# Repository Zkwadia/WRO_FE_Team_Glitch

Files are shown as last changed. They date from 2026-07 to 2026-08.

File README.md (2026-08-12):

# 🚗 WRO 2026 Future Engineers — Team Glitch

<div align="center">



</div>

---

## 🏆 WRO 2026 Future Engineers — India Nationals

Welcome to the GitHub repository of **Team Glitch**, competing in the **World Robot Olympiad™ (WRO®) Future Engineers 2026** category at the India National Finals. Our team is made up of students who designed, built, and programmed a fully autonomous self-driving vehicle to tackle the dynamic challenges of the WRO 2026 competition.

Our name, **Glitch**, reflects our engineering philosophy — finding the unexpected edge cases, the subtle bugs, and the tiny mis-alignments that make the difference between a run that scores and a run that doesn't. We don't just build a robot; we debug it relentlessly until every glitch is gone.

> *"Every test run is a debugging session. Every crash is data."*

**Current best times on the 3m × 3m field:**
- **Open Challenge**: ~50 seconds (full score)
- **Obstacle Challenge**: ~72 seconds (full score)
  
---

## 📚 Table of Contents

- [📂 Documentation Structure](#-documentation-structure)
- [👥 The Team](#-the-team)
- [🎯 Challenge Overview](#-challenge-overview)
- [🤖 Our Robot](#-our-robot)
- [🔧 Electronic Systems & Components](#-electronic-systems--components)
- [⚙️ Mechanical Systems](#️-mechanical-systems)
- [💻 Software Architecture](#-software-architecture)
- [🧭 Open Challenge — Strategy & Logic](#-open-challenge--strategy--logic)
- [🚧 Obstacle Challenge — Strategy & Logic](#-obstacle-challenge--strategy--logic)
- [🔄 Engineering Decisions & Iterations](#-engineering-decisions--iterations)
- [📹 Performance Videos](#-performance-videos)
- [🌐 GitHub Utilization](#-github-utilization)
- [📜 License](#-license)
- [🗓️ GitHub Commit Dates](#github-commit-dates)

---

## 📂 Documentation Structure

Each folder in this repository contains detailed technical content:

| Folder | Content | 
|---|---|
| `v-photos/` | Robot photos — 6 angles + labelled component view |
| `t-photos/` | Team photos — official and fun |
| `schemes/` | Wiring diagram, power architecture |
| `models/` | 3D print STL files, STEP CAD files for polycarbonate cuts |
| `src/` | Main Python scripts — obstacle and open challenge |
| `versionTest/` | Test Python scripts — All modules testing|
| `other/` | Component images used in this README |

---

## 👥 The Team

**Official Team Photo**

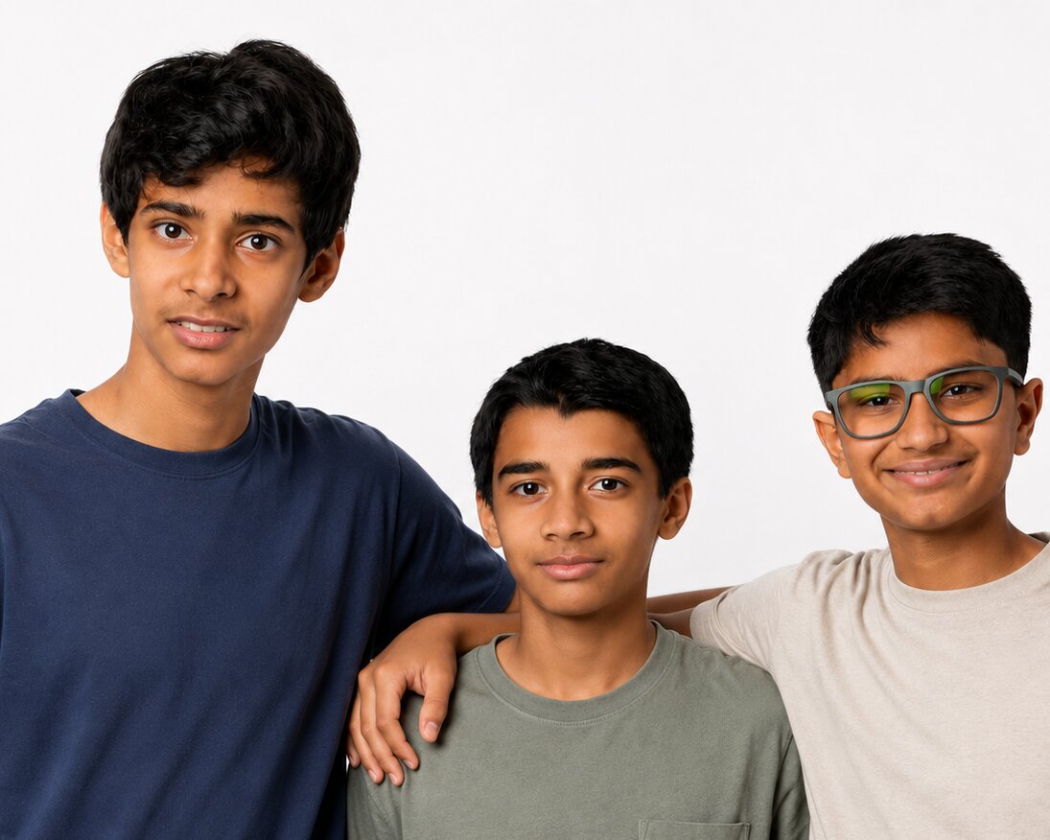
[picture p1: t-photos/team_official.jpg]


---

| Member | Role | Background | About |
|---|---|---|---|
| **Shaurya Sule** | Documentation, Electronics, Strategy | 9th Grade | Shaurya is a Grade 9 student at Dhirubhai Ambani International School with a strong interest in robotics and debate. He has participated in WRO multiple times, including competing at the World Championships and achieving 3rd place. He is also the captain of his FTC team, where he develops leadership, engineering, and problem solving skills. Alongside robotics, he is an accomplished debater and has won multiple debate championships across India.|
| **Rehaan Dhandhia** | Software, Vision & Sensor Integration | 9th Grade | Rehaan is a Grade 9 student at Dhirubhai Ambani International School. He has participated in WRO for four years and achieved 3rd place at the WRO World Finals in 2023. He has also been involved in FIRST Tech Challenge (FTC) for the past two years. Through robotics, he has developed skills in programming, electronics, and problem solving. Outside robotics, he enjoys mathematics and physics, has played the piano for eight years, and has competed in state level badminton tournaments.|
| **Zeus Wadia** | Electronics, Testing, Mechanical Design | 9th Grade | Zeus is a Grade 9 student at Nita Mukesh Ambani Junior School, Mumbai, with a strong interest in robotics and engineering. He has competed in WRO and FTC, gaining experience in robot design, electronics, programming, and autonomous systems. In 2025, he placed 12th at the WRO Future Innovators Junior National Finals and has participated in FTC for the past two years.|

**Coach:** **Ajinkya Giri** — Robotics Engineer and Mentor

**Fun Team Photo:**
This photo is from the 2025 WRO India nationals, where the 3 of us competed as a team in the Future Innovators category and eventually placed 12th.
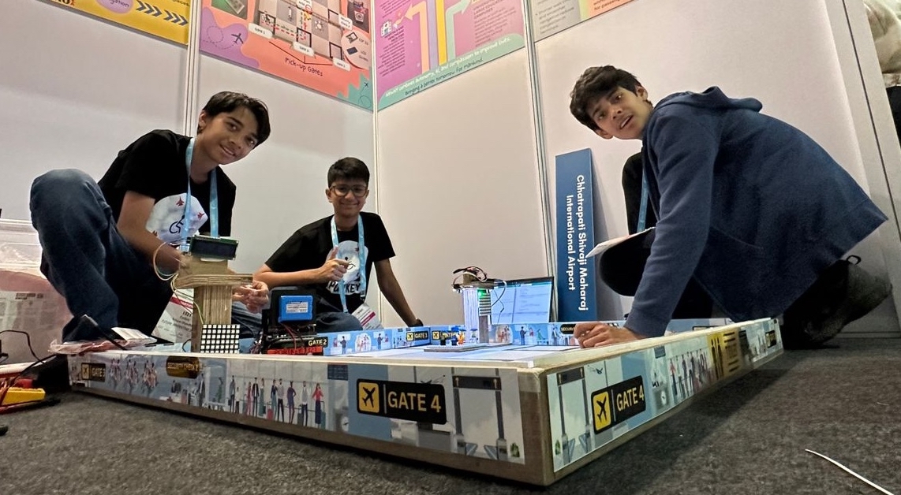
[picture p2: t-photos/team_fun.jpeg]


### Team Journey

Throughout development — from first chassis cut to nationals — we logged every run, debugged every crash, and iterated on every subsystem. The photos below capture key moments from that process.

**Testing session photo:** Tuning robot parking (setting up obstacle challenge).

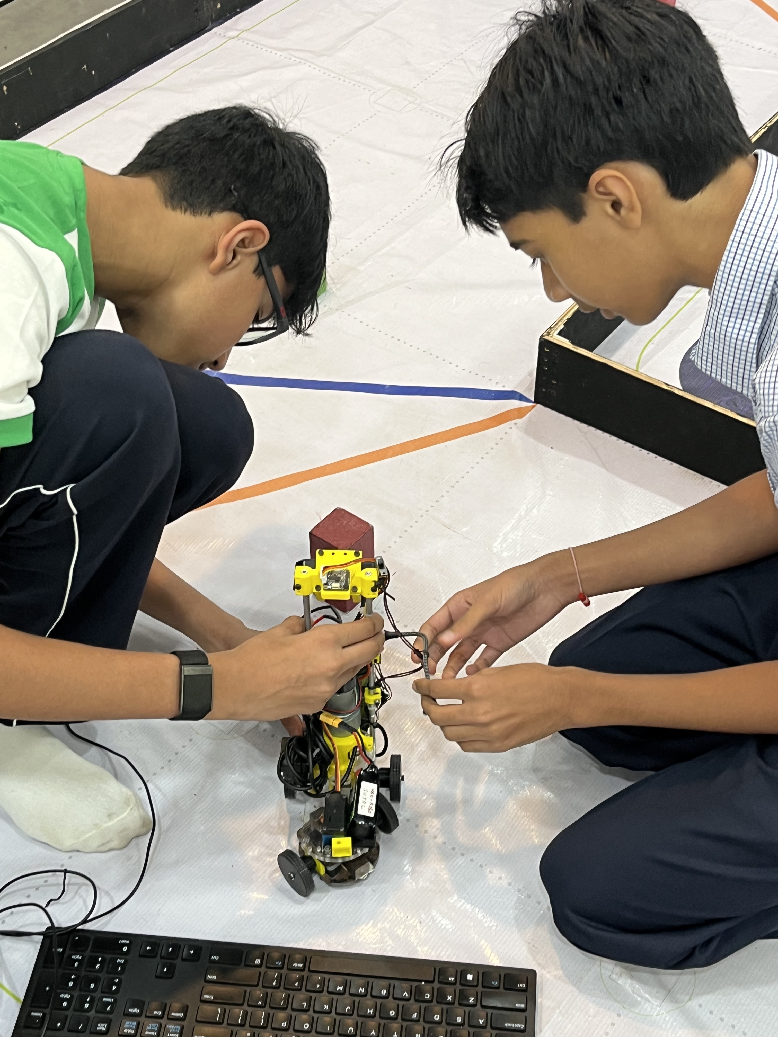
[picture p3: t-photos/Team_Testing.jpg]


---

## 🎯 Challenge Overview

WRO 2026 Future Engineers is a self-driving car challenge on a 3m × 3m racetrack that changes configuration every round.

### Open Challenge

| Aspect | Requirement | Our Approach |
|---|---|---|
| **Track Variability** | Random internal wall placements | Outer wall centroid PD — adapts to any corridor width |
| **Navigation** | Unknown layout each round | Camera wall detection + IMU heading hold |
| **Lap Count** | 3 laps, stop at start | Counter + `last_wall` camera zone + IMU heading snap |
| **Speed** | Sub-60s target | 85% PWM, smoothed ramp, no speed PID needed |

### Obstacle Challenge

| Aspect | Requirement | Our Approach |
|---|---|---|
| **Traffic Signs** | Red → right, Green → left | OpenCV HSV centroid PD, 2-state avoidance |
| **Lap Count** | 3 laps | Floor line colour trigger, encoder odometry |
| **Parking** | Fully inside lot, parallel to wall | 4-state parking state machine + TFmini Plus proximity |
| **Direction** | Detected at start | Side wall distance + outer wall camera zone |

### WRO 2026 Documentation Scoring (30 Points)

| Area | Max Points | Our Coverage |
|---|---:|---|
| **1. Mobility & Mechanical Design** | 6 | Motor selection, Parallel steering system, custom polycarbonate chassis, drive system, encoder integration |
| **2. Power & Sensor Architecture** | 6 | Dual rail power system, TFmini Plus LiDAR, BNO085 IMU, sensor placement, wiring diagrams |
| **3. Software Architecture & Obstacle Strategy** | 6 | State machines, HSV vision pipeline, centroid based PD control, obstacle avoidance logic, parking sequence, source code |
| **4. Systems Thinking & Engineering Decisions** | 6 | Design iterations, subsystem integration, engineering tradeoffs, decision rationale, risk mitigation |
| **5. Reproducibility & GitHub Quality** | 6 | Structured repository, commit history, README, CAD files, wiring diagrams, full documentation, replication guide |
| **Total** | **30** | |

### Educational Objectives

- **Computer Vision**: Real-world HSV colour segmentation, zone-based detection, LAB colour space
- **Control Systems**: PID steering, closed-loop speed control, positional vs. incremental PID
- **Embedded Systems**: Multiprocessing on Linux, UART communication, I2C sensor management
- **Systems Engineering**: Process isolation, shared memory, fault recovery
- **Engineering Documentation**: Decision rationale, iteration history, replication guides

---

## 🤖 Our Robot

<div align="center">

<table>
  <tr>
    <td align="center"><b>Front View</b></td>
    <td align="center"><b>Rear View</b></td>
  </tr>
  <tr>
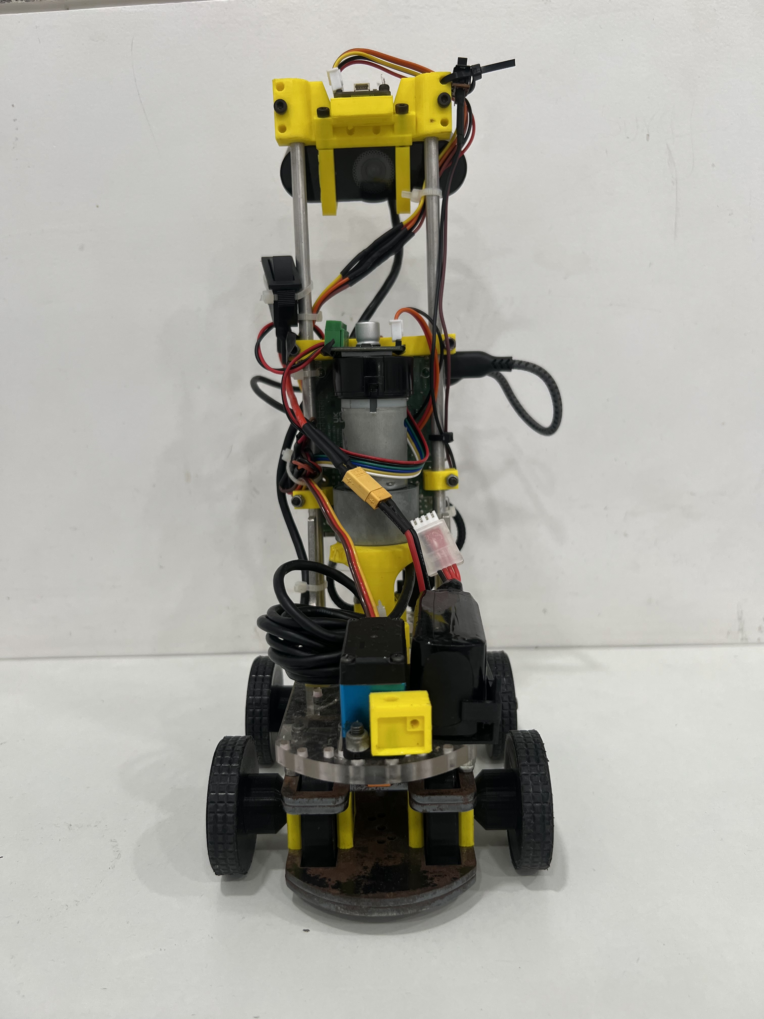
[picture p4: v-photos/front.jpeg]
    <td></td>
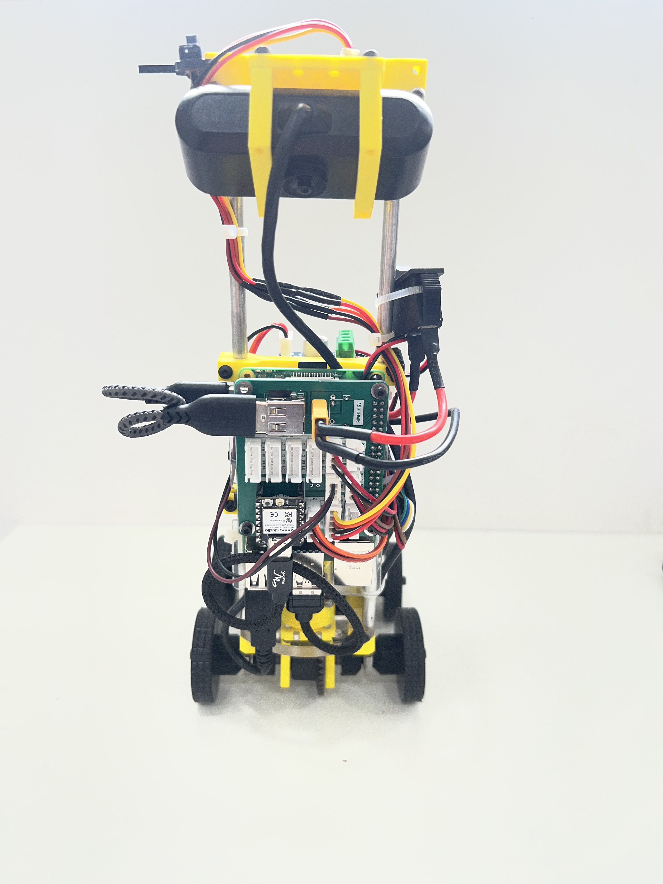
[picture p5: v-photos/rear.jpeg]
    <td></td>
  </tr>
  <tr>
    <td align="center"><b>Left Side</b></td>
    <td align="center"><b>Right Side</b></td>
  </tr>
  <tr>
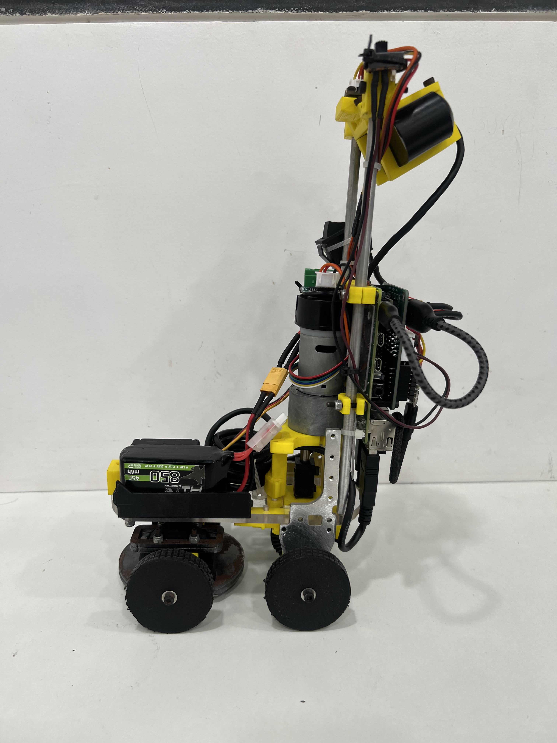
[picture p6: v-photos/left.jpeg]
    <td></td>
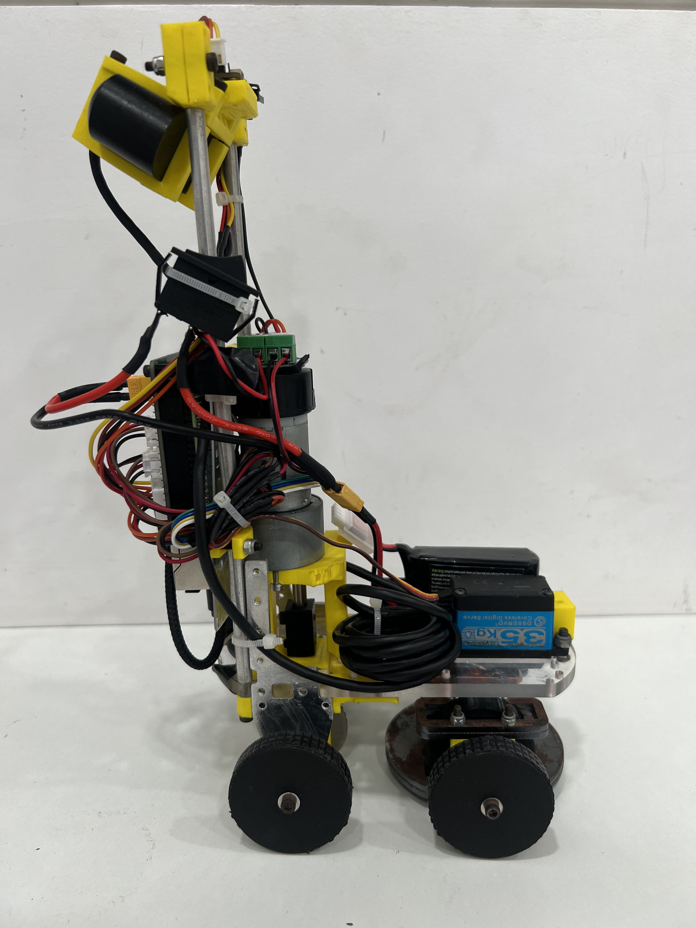
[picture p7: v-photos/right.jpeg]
    <td></td>
  </tr>
  <tr>
    <td align="center"><b>Top View</b></td>
    <td align="center"><b>Bottom View</b></td>
  </tr>
  <tr>
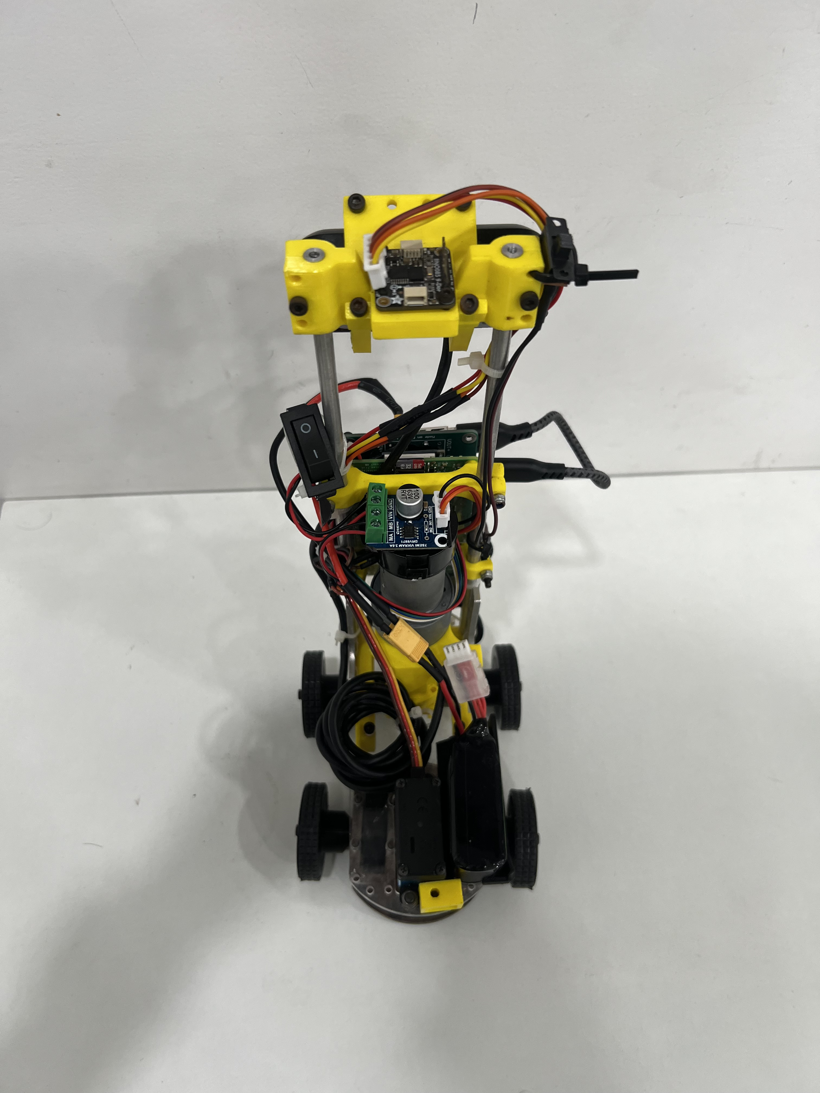
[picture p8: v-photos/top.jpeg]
    <td></td>
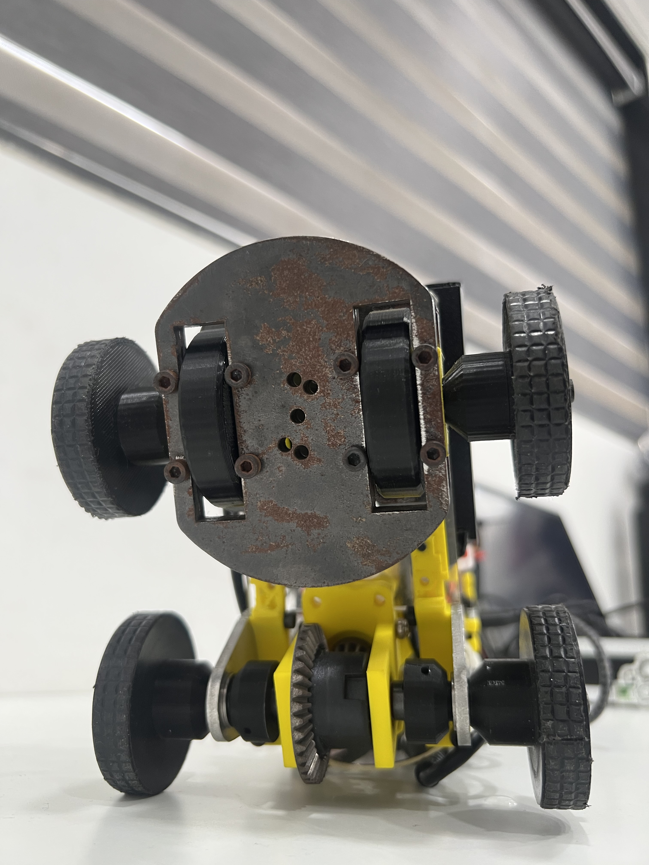
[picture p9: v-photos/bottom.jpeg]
    <td></td>
  </tr>
  <tr>
    <td colspan="2" align="center"><b>Labelled Component View</b></td>
  </tr>
  <tr>
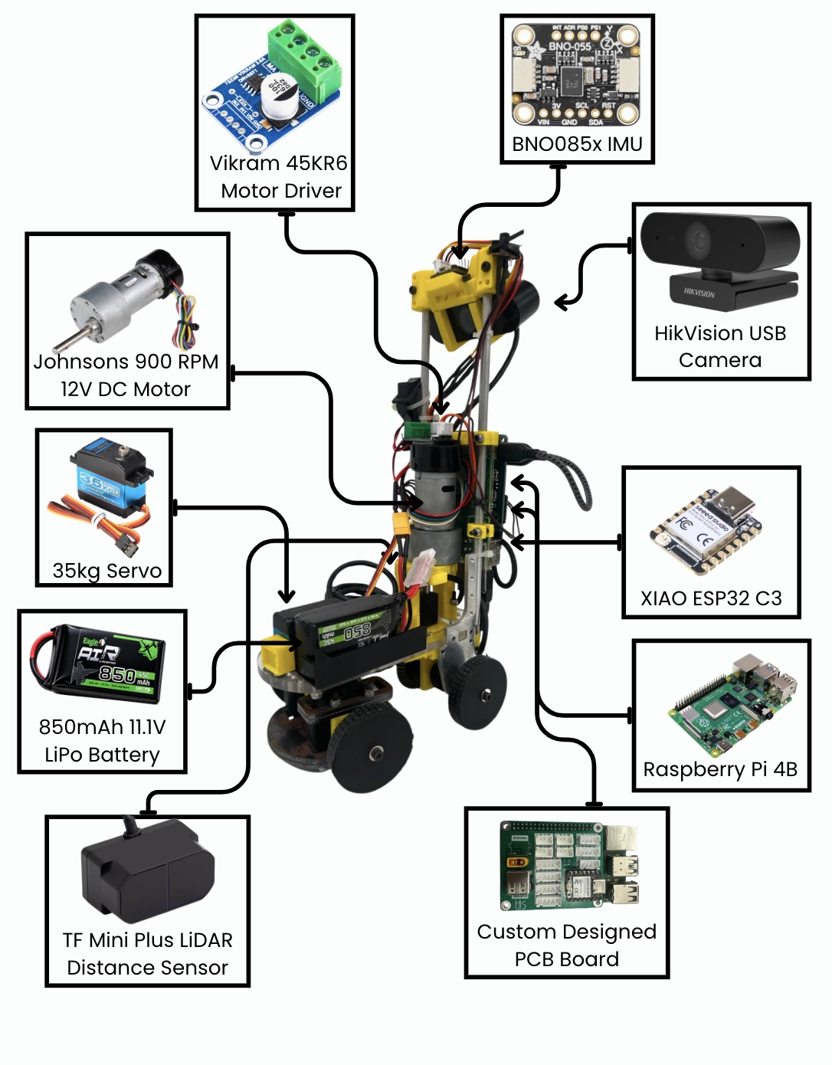
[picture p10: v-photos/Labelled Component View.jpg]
    <td colspan="2" align="center"></td>
  </tr>
</table>

</div>

### Key Specifications

| Parameter | Value |
|---|---|
| **Dimensions** | [190] × [120] × [300] mm |
| **Weight** | ~[1.310] kg |
| **Drive Type** | Rear-wheel drive, 12V DC geared motor + external quadrature encoder |
| **Steering** | Servo-actuated parallel steering system |
| **Primary Brain** | Raspberry Pi 4 Model B (4 GB) |
| **Co-processor** | Seeed XIAO ESP32-C3 (IMU + encoder over USB UART) |
| **Vision** | USB Camera + OpenCV HSV pipeline (no Edge TPU) |
| **Distance Sensor** | 1× TFmini Plus LiDAR (right side, UART, parking only) |
| **Heading** | Adafruit BNO085 9-DOF IMU (on XIAO, I2C) |
| **Max Speed** | ~90% PWM duty cycle |

### Performance Specifications

| Metric | Value |
|---|---|
| **Max theoretical speed** | ~[2] m/s (from 900RPM + wheel diameter) |
| **Operational speed** | ~[2.703] m/s (90% PWM, closed-loop) |
| **Battery capacity** | [850] mAh LiPo |
| **Camera FPS (live loop)** | ~25 FPS (with `cv2.imshow` disabled) |
| **IMU update rate** | 100Hz (BNO085 Euler output) |
| **UART baud rate** | 115200 (XIAO → Pi) |

---

## 🔧 Electronic Systems & Components

### Component List

| Component | Image | Specifications | Role | Source |
|---|---|---|---|---|
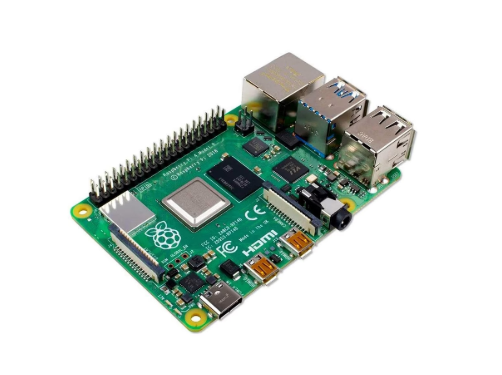
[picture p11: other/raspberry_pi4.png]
RPi4
| **Raspberry Pi 4 Model B (4GB)** |  | Quad-core Cortex-A72 @ 1.8GHz, 4 GB LPDDR4, USB 3.0, GPIO 40-pin | Main compute — vision, sensor fusion, PID control via pigpio | [robu.in](https://robu.in/product/raspberry-pi-4-model-b-with-4-gb-ram/) |
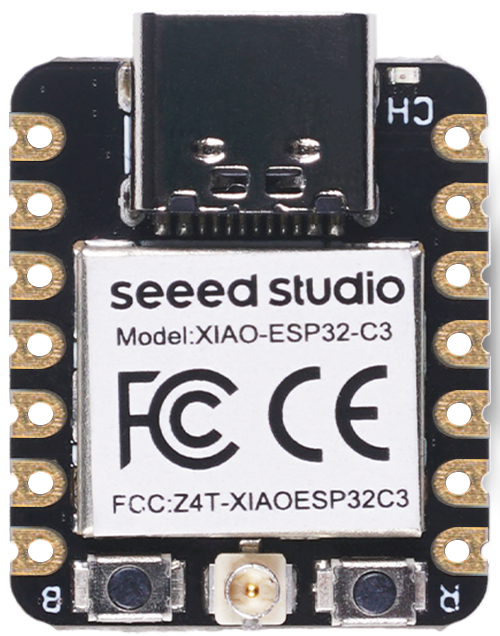
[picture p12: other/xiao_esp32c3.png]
XIAO
| **Seeed XIAO ESP32-C3** |  | ESP32-C3 RISC-V @160MHz, 400KB SRAM, USB-C, 3.3V logic, 21×17.5mm | Co-processor — BNO085 IMU + external encoder, streams to Pi at 115200 baud | [robu.in](https://robu.in/product/seeed-studio-xiao-esp32c3/) |
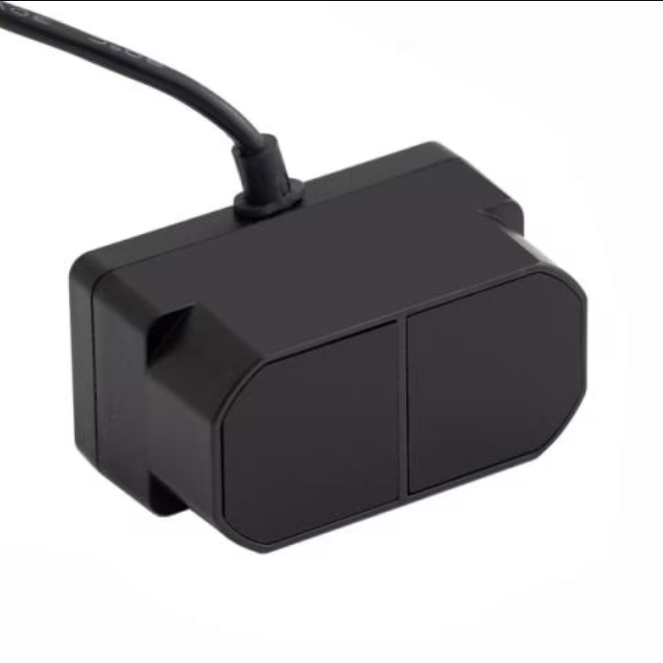
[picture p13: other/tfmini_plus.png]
TFmini Plus
| **Benewake TFmini Plus LiDAR ×1** |  | 0.1–12m, ±5cm accuracy, 3.6° FOV, UART 115200, 5V, IP65, 42×15×16mm | Right-side parking proximity — when `distance < 150mm` parking approach confirmed | [robu.in](https://robu.in/product/tfmini-plus-lidar-distance-sensor-for-drones-uav-uas-robots-12m/) |
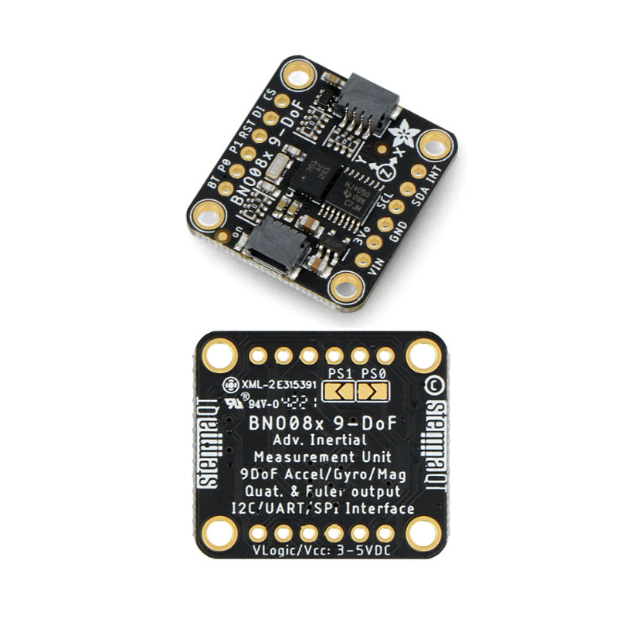
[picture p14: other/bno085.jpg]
BNO085
| **Adafruit BNO085 IMU** |  | 9-DOF, ARM Cortex-M0 fusion, Euler @100Hz, I2C | Absolute heading for PID steering — prevents drift across all 3 laps | [evelta.com](https://evelta.com/adafruit-bno085-9-dof-orientation-imu-fusion-breakout/) |
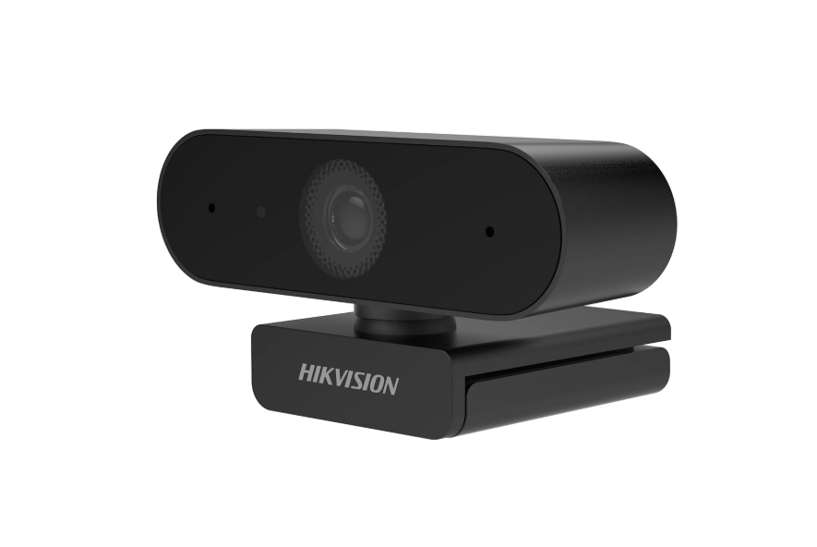
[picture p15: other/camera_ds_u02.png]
Camera
| **USB Camera** |  | 2MP, 1080P @ 30fps, ultra-wide, USB 2.0 | HSV pipeline input — detects pillars, parking markers, floor lines, walls | [amazon.in](https://www.amazon.in/HIKVISION-DS-U02-Distortion-Adjustment-Conferencing/dp/B0929FSQ2J) |
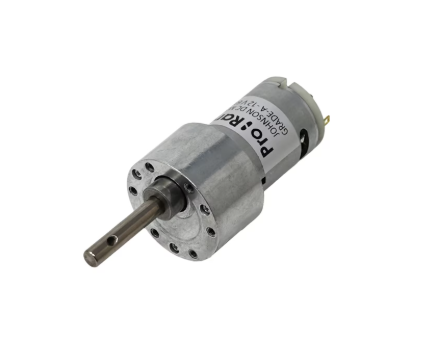
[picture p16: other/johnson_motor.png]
Johnson900
| **Johnson 900RPM Grade A** (RKI-1142) |  | 12V DC, 900RPM no-load, high-torque grade-A gearbox, no built-in encoder | Rear-wheel drive via Vikram-453R6. External encoder on output shaft | [robokits.co.in](https://robokits.co.in/motors/dc-motor/12v-johnson-motors/johnson-geared-dc-motors/johnson-motor-high-torque-dc-geared-12v-900rpm-grade-a) |
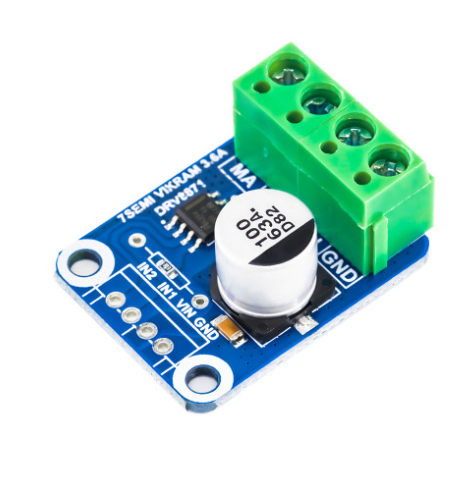
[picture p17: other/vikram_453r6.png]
Vikram453R6
| **7Semi Vikram-453R6** |  | DRV8871, 6.5–45V, 2A cont / 3.6A peak, IN1/IN2 PWM, thermal protection | Motor driver — IN1=GPIO16, IN2=GPIO20. Auto-recovery on overcurrent | [7semi.com](https://7semi.com/7semi-vikram-453r6-dc-motor-driver-breakout-6-5v-45v-input-3-6a-single-channel/) |

**Component Selection Philosophy:** We prioritize components that are widely available in India, well-documented, and separable by concern — the Pi handles vision and decisions, the XIAO handles timing-critical encoder counting, and the TFmini Plus handles parking proximity without sharing the I2C bus. Every component was chosen because it solves a specific, tested problem.

### Power Architecture

The robot uses a **dual-rail power system** — motor on 12V direct, all electronics on regulated 5V. This was non-negotiable after early testing showed motor PWM spikes causing 40°+ BNO085 heading jumps on a single-rail setup.

```
[12V LiPo Battery]
       |
       ├── [Vikram-453R6 (IN1=GPIO16, IN2=GPIO20)] ──> Johnson 900RPM Motor
       |
       └── [5V Buck Converter]
                   |
                   ├── Raspberry Pi 4 (5V/3A USB-C)
                   │       └── [Pi UART /dev/ttyAMA1] ──> TFmini Plus right (5V)
                   ├── Servo UBEC (dedicated ≥5A)
                   │       └── DS3235 servo signal → GPIO8
                   └── Seeed XIAO ESP32-C3 (via Pi USB-C)
                           └── [XIAO 3V3 rail] ──> BNO085 IMU (I2C)
                                                    External encoder (GPIO)

[I2C — XIAO only]     XIAO ←→ BNO085 (3.3V)
[UART — Pi ttyAMA1]   TFmini Plus right → Pi
[UART — Pi XIAO_USB]  XIAO → Pi — heading (float) + counts (int)
[USB]                 Camera → Pi /dev/video0
```

**Power budget:**

| Component | Voltage | Current |
|---|---|---|
| Johnson 900RPM (loaded) | 12V | ~400mA typical, ~2A stall |
| Raspberry Pi 4 | 5V | 1.0–1.5A |
| XIAO ESP32-C3 | 5V via Pi USB | 25–40mA |
| TFmini Plus ×1 | 5V | 110mA avg |
| DS3235 servo | 5–6V UBEC | 5mA idle, ~2A stall |
| **Total peak (referred to 12V)** | — | **~3.0A** |

### Wiring Diagram

<div align="center">
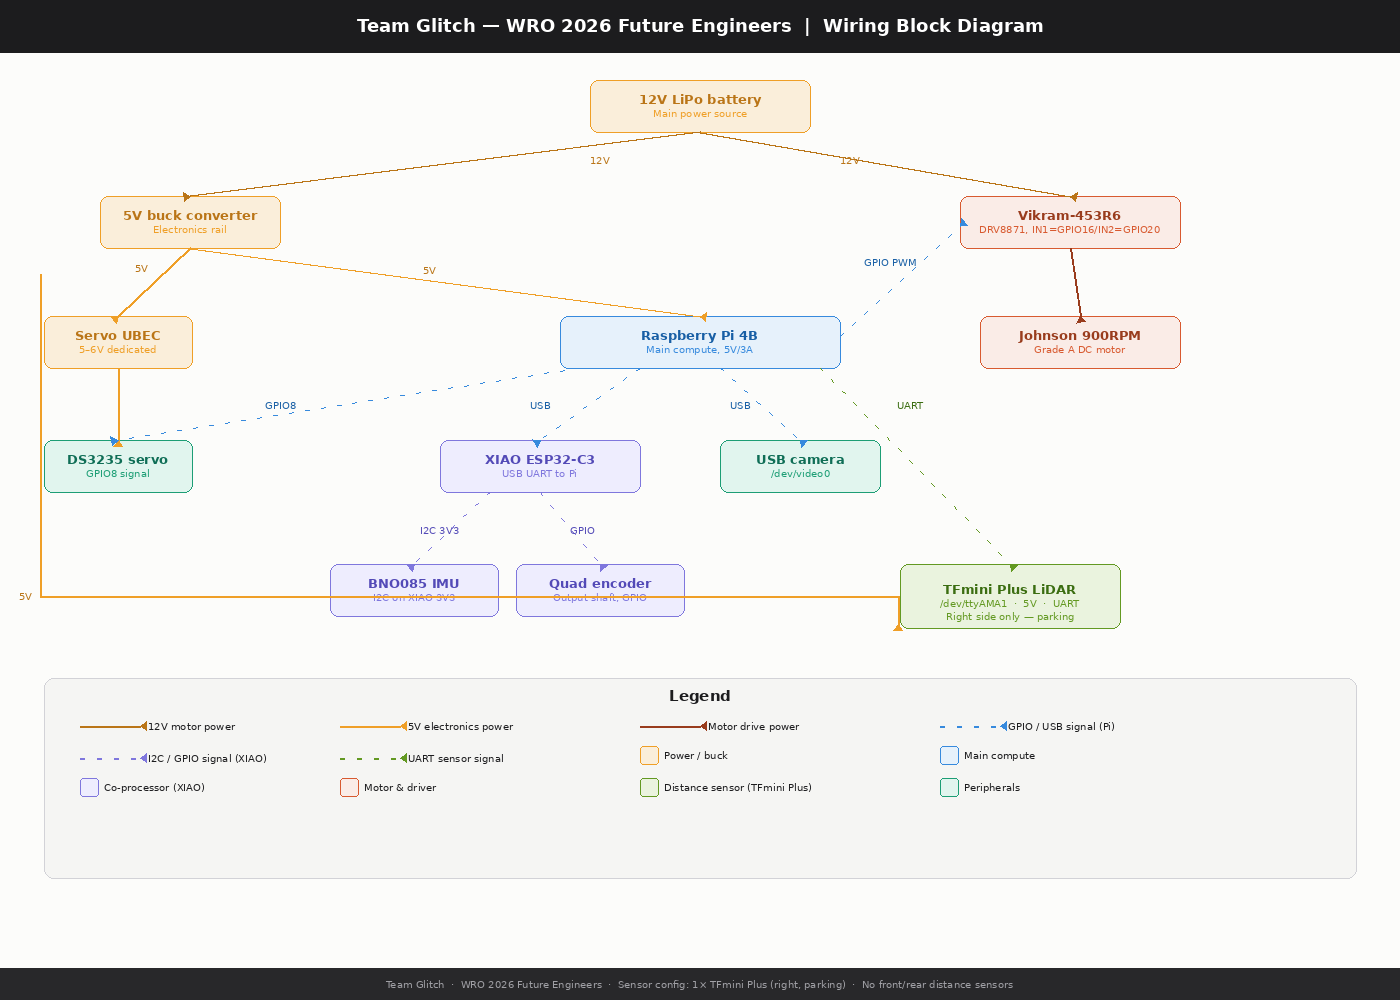
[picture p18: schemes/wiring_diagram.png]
  
</div>

### GPIO Pin Assignment

| GPIO / Interface | Function | Direction |
|---|---|---|
| GPIO6 | Kill switch input | IN |
| GPIO8 | DS3235 servo PWM | OUT |
| GPIO13 | Red LED | OUT |
| GPIO16 | Vikram IN1 — forward PWM | OUT |
| GPIO19 | XIAO reset | OUT |
| GPIO20 | Vikram IN2 — reverse PWM | OUT |
| GPIO26 | Blue LED | OUT |
| /dev/ttyAMA1 | TFmini Plus right (UART RX) | IN |
| /dev/XIAO_USB | XIAO ESP32-C3 (UART) | IN/OUT |
| /dev/video0 | USB camera | IN |

### Sensor Placement Rationale

**TFmini Plus — Right side (`/dev/ttyAMA1`):** Mounted at 60mm from ground on the right flank, perpendicular to travel. Used only during parking approach. Its 3.6° laser spot reads the outer wall cleanly — the VL53L0X it replaced had a 25° FOV that picked up floor reflections below 80mm. Mounting at 30mm initially caused this problem; 60mm resolved it.

**Camera:** Front-facing, slight downward angle. Exposure fixed at `CAP_PROP_EXPOSURE = -6` — without this, auto-exposure flicker between light/dark mat sections caused false negatives on every orange line crossing.

**BNO085 IMU:** On the XIAO, powered from XIAO 3V3 only, positioned ≥80mm from the Johnson motor and Vikram driver. At 40mm we measured 3° drift per stall event — moving to 80mm eliminated this.

### Power Management — Engineering Note

During early testing we found the Pi's 3V3 rail was insufficient to power the BNO085 cleanly when the motor was under load. The fix was to power the BNO085 exclusively from the XIAO's own 3V3 regulator, which is isolated from the Pi's rail entirely. This is why the XIAO is powered via USB from the Pi (5V) but the BNO085 never touches the Pi's 3V3 pin.

---

## ⚙️ Mechanical Systems

### Chassis Design

<div align="center">
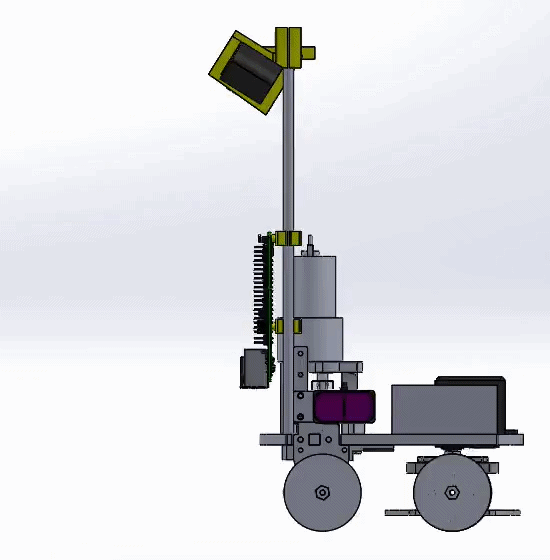
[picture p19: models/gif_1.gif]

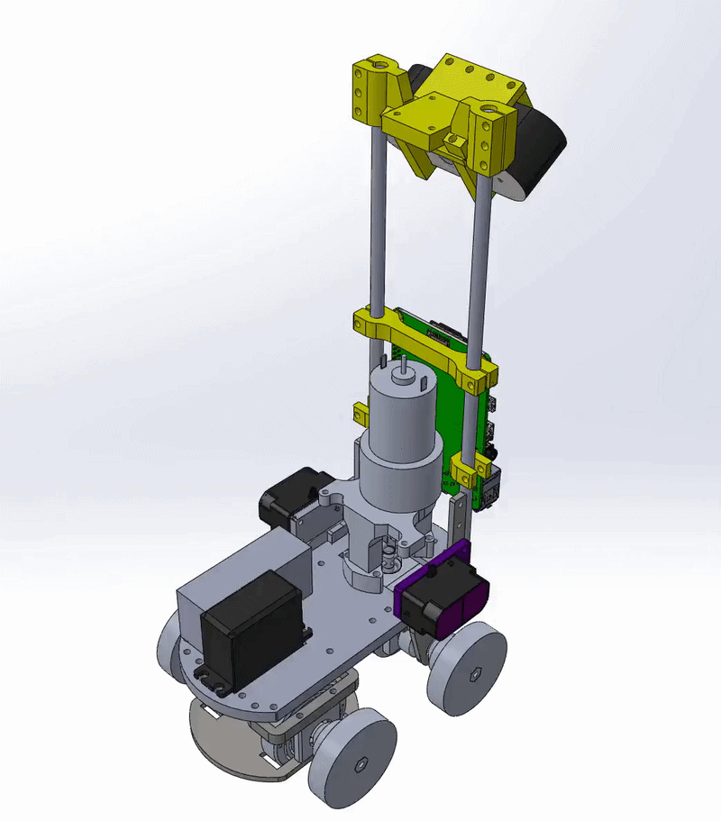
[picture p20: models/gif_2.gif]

</div>
The chassis and electronics tray are laser-cut or CNC-cut from polycarbonate sheet (6mm chassis, 3mm tray) — not 3D printed. The rear axle is driven by the Johnson 900RPM motor via direct coupling. The front axle using a parallel steering system  actuated by the DS3235 35kg Servo.

**Why Parallel Steering?** We first considered using Ackerman geometry to reduce wheel skid and tyre scrub, however, this system was extremely bulky. Instead, we decided to use a compact, lightweight parallel steering linkage, which helped us make our bot more compact and balanced.

**Acknowledging Trade-Offs:**
A parallel steering linkage makes the inner wheel skid on tight turns because each wheel follows a different radius. However, using custom designed wheels coated with cat-tongue grip tape helped us minimise tyre deformation.

### Drive System

**Motor Selection:**

| Option | RPM | Torque | Verdict |
|---|-----|---|---|
| Johnson 300 RPM | 300 | ~8 kg·cm | Too slow for sub-60s laps |
| Johnson 600 RPM | 600 | 4.5 kg·cm | Prior season — adequate but limited top speed |
| Rhino GB37 1000RPM | 1000 | 0.7 kg·cm | Tested — stalled at low PWM, insufficient torque |
| **Johnson 900RPM Grade A ✓** | **900** | **3 kg.cm** | **Current — best torque/speed balance, external encoder added** |

**Drive train calculation:**

```
Motor speed    = 900 RPM
Wheel diameter = [44] mm

Linear speed = (RPM / 60) × π × D
             = (900 / 60) × π × [44/1000]
             ≈ [2.073] m/s at 100% PWM
```

The Johnson 900RPM has no built-in encoder. An external quadrature encoder is mounted on the output shaft and read by the XIAO ESP32-C3. `SPEED_SCALE` (counts/sec at 100% duty) must be calibrated from run logs before enabling `ki_v` or `kd_v`.

**Motor Driver:** The Vikram-453R6 (DRV8871) replaced the MDD3A after two driver failures — the MDD3A has no overcurrent protection. The DRV8871 adds hardware overcurrent detection, thermal shutdown, and auto-recovery. Its 45V ceiling handles inductive spikes. The IN1/IN2 PWM interface is pin-compatible with MDD3A so no code changes were needed.

**Reducing Tyre Skid: Differential Gearbox:**
Since while turning, both wheels follow a different turning radius, we decided to use a differential gearbox, which allows the wheels to rotate at different speeds while turning, reducing wheel slippage and improving traction. It uses a ring gear, spider gear, and side gears connected to the wheels, allowing the outer wheel to rotate faster and the inner wheel slower during turns while maintaining a constant motor speed.

### Structural Analysis

| Metric | Value |
|---|---|
| Chassis material | 6mm polycarbonate (CNC cut) |
| Electronics tray | 3mm polycarbonate |
| Motor mount hardware | M3 bolts |
| Servo mount | Press-fit into servo bay with M3 bolts |
| TFmini Plus mount | `tf mini mount horizontal.STL` at 60mm height |
| Camera tilt | Fixed 32° downward (`new camera mount.STL`) |

### Iteration History

<div align="center">
  
</div>

**Version 1 — National 2025:**
- Raspberry Pi + Arduino Mega co-processor
- Google Coral Edge TPU for object detection (TFLite quantized model)
- RPLidar C1 for turn detection
- Johnson 600RPM motor, MDD3A driver
- Problem: Parking unreliable — single-pass approach overshot; LiDAR subprocess complex and slow

**Version 2 — Nationals 2026 (Current):**
- Replaced Arduino Mega + Coral TPU + RPLidar with leaner stack:
  - **XIAO ESP32-C3** — BNO085 IMU + external encoder over USB UART
  - **1× TFmini Plus** (right only) — parking proximity over UART
  - **OpenCV HSV pipeline** — replaces Edge TPU ML model entirely
- Switched to **Johnson 900RPM Grade A** + external encoder
- Switched to **Vikram-453R6** (DRV8871) — overcurrent protection
- Camera FPS improved from ~5 to ~25 by removing `cv2.imshow` from live loop
- Hot-reloadable `gains.json` — change PID gains without restarting

### Potential Future Improvements

- Switch to a motor with a built-in encoder to eliminate the external encoder mount complexity
- Add a rear-facing camera or second TFmini for reverse safety during parking
- Replace polycarbonate tray with a custom PCB carrier for better wire management
- Implement automatic `SPEED_SCALE` calibration from the first run's log file

---

## 💻 Software Architecture

The software runs on the Raspberry Pi 4 using Python's `multiprocessing` module. Four OS processes run concurrently on separate CPU cores, communicating via `multiprocessing.Value` shared memory. This prevents slow camera inference from blocking the time-critical steering loop.

### Process Architecture

```
┌──────────────────────────────────────────────────────┐
│                     Main Process                      │
│          Spawns all child processes, exits            │
└──────┬──────────────┬────────────────┬───────────────┘
       │              │                │              │
┌──────▼──────┐ ┌─────▼──────┐ ┌──────▼──────┐ ┌────▼───────────┐
│CameraProcess│ │IMUandEncoder│ │ TOFProcess  │ │  DriveProcess  │
│  (P)        │ │  (E)        │ │  (T)        │ │  (S) MAIN LOOP │
│ OpenCV HSV  │ │ /dev/XIAO   │ │ spawned but │ │ Reads ALL      │
│ pipeline    │ │ _USB UART   │ │ TFmini read │ │ shared memory  │
│ → red_b     │ │ → head.value│ │ directly in │ │ PID steering   │
│ → green_b   │ │ →counts.val │ │ DriveProcess│ │ Speed PID      │
│ → pink_b    │ │             │ │             │ │ State machine  │
│ → wall_*    │ │             │ │             │ │ Motor + servo  │
└─────────────┘ └─────────────┘ └─────────────┘ └────────────────┘
```

> **Note on TFmini Plus:** The TFmini Plus is instantiated as `TFmini(17, 27, 25, 24)` inside `DriveProcess` and polled directly via `tfmini.getTFminiData()` each loop. It is not routed through `TOFProcess` — `distance_head` is read as `tf_l` directly in the drive loop.

**Why multiprocessing over threading?** Python's GIL prevents threads from running CPU-bound tasks truly in parallel. `multiprocessing` spawns real OS processes — each with its own GIL — so `CameraProcess` (OpenCV) and `IMUandEncoder` (UART reads) run on separate Pi 4 cores simultaneously.

### Shared Variables (cross-process, lock-protected)

| Variable | Type | Written by | Read by | Purpose |
|---|---|---|---|---|
| `head` | float | IMUandEncoder | DriveProcess | IMU heading (°) from BNO085 |
| `counts` | int | IMUandEncoder | DriveProcess | Encoder count for odometry + speed PID |
| `red_b` | bool | CameraProcess | DriveProcess | Red pillar visible |
| `green_b` | bool | CameraProcess | DriveProcess | Green pillar visible |
| `pink_b` | bool | CameraProcess | DriveProcess | Magenta parking marker visible |
| `centr_x/y` | float | CameraProcess | DriveProcess | Green pillar centroid |
| `centr_x_red/y_red` | float | CameraProcess | DriveProcess | Red pillar centroid |
| `centr_x_pink/y_pink` | float | CameraProcess | DriveProcess | Pink marker centroid |
| `wall_left/right` | double | CameraProcess | DriveProcess | Inner wall centroid-X |
| `outer_wall_left/right` | double | CameraProcess | DriveProcess | Outer wall centroid-X |
| `close_wall` | double | CameraProcess | DriveProcess | Close wall area — turn/parking |
| `park_wall` | double | CameraProcess | DriveProcess | Parking wall area |
| `last_wall` | double | CameraProcess | DriveProcess | End-wall area — parking trigger + open stop |
| `orange_l / blue_l` | bool | CameraProcess | DriveProcess | Floor line colour — lap direction |
| `switch_state` | bool | DriveProcess | CameraProcess | Kill-switch state |

### XIAO UART Protocol

The XIAO ESP32-C3 firmware streams sensor data to the Pi at 115200 baud:

**Output format (every loop):**
```
<heading_float> <encoder_int>\n
Example: 91.34 2841
```

**Commands accepted from Pi:**

| Command | Effect |
|---|---|
| `b"R"` | Software reset — reboots XIAO and reinitialises BNO085 |
| `b"1"` | Zero the encoder count |

### PID Steering Control (`correctAngle`)

```python
error_gyro = heading - setPoint_gyro
if error_gyro > 180:
    error_gyro -= 360           # handle wraparound

pTerm = kp * error_gyro * multiplier   # kp = 0.6
dTerm = kd * ((error_gyro - prevErrorGyro) / dt)  # kd = 0.01
correction = pTerm + dTerm
correction = max(-25, min(25, correction))

servo.setAngle(95 - correction)   # 95° = mechanical centre (obstacle)
                                  # 90° = mechanical centre (open)
```

`multiplier` values: `1.0` = straight-line hold, `1.5` = normal driving, `3.0` = tight parking turns. `correctReverseAngle` uses `95 + correction` for reverse maneuvers.

### Obstacle Avoidance — Centroid PD

```python
# Target centroid X positions for each colour + state
if green_b.value:
    err = 340 - centr_x          # state 1 (far)
    err = 520 - centr_x          # state 2 (close, centr_y > 100)
    # blue direction + wall visible: 320 / 470
elif red_b.value:
    err = 300 - centr_x_red      # state 1
    err = 120 - centr_x_red      # state 2
    # orange direction + wall visible: 320 / 170

servo_angle = err * kp_s + ((err - prev_err) / dt_main) * kd_s
servo_angle = max(-30, min(30, servo_angle))
servo.setAngle(95 - servo_angle)
```

State 2 lasts 0.08s then resets to state 1, or resets early when `centr_y_pink > 100` or `close_wall > 50`. When no block is visible and one inner wall is detected, a fixed `±15` err nudge centers the robot. When outer walls are visible without blocks, heading is corrected by `heading_angle ± 5°`.

### Speed PID (`correctSpeed`)

Positional PID — output recomputed fresh each call, not accumulated:

```python
actual_cps = raw_delta / dt           # encoder counts per second
target_cps = target_power_pct * SPEED_SCALE / 100.0
error = target_cps - actual_cps

total_error_speed += error * dt
total_error_speed = max(-500, min(500, total_error_speed))   # anti-windup

correction = kp_v * error + ki_v * total_error_speed + kd_v * (error - prev_error) / dt
duty = target_power_pct + correction   # baseline + correction — NOT accumulated
duty = max(0.0, min(100.0, duty))
```

Auto-resets on direction flip. `SPEED_SCALE` must be calibrated from run logs — the default in `gains.json` is `0.0` as a reminder.

### Vision Pipeline

`CameraProcess` runs either `vision_pipeline_new.py` (obstacle) or `vision_pipeline_3.py` (open). Both are pure OpenCV — no ML accelerator.

**Pipeline steps:**
1. Capture frame via `cap.read()` — buffer size = 1 so always latest frame
2. Resize to `FRAME_WIDTH × FRAME_HEIGHT`
3. Convert to HSV (and LAB if `USE_LAB = True`)
4. Threshold per colour class per zone
5. Find contours, filter by area minimum
6. For each zone: pick largest blob by area (or lowest by centroid-Y = closest)
7. Write centroid/area/flag to shared memory

**Camera settings:**
```python
cap.set(cv2.CAP_PROP_EXPOSURE, -6)   # fixed — no flicker on mat transitions
cap.set(cv2.CAP_PROP_BUFFERSIZE, 1)  # always newest frame — critical at 25fps
```

| Colour | Zones | Role |
|---|---|---|
| Red | `main`, `close` | Red pillar |
| Green | `main`, `close` | Green pillar |
| Magenta | `main`, `close` | Parking lot boundary |
| Orange | `line`, `line_2` | CW floor line |
| Blue | `line`, `line_2` | CCW floor line |
| Black | `wall_inner_left/right`, `wall_left/right`, `close_black`, `parking_wall`, `last_wall`, `last_wall_2` | Walls + parking zones |

When red and green are both visible, the closer one (larger centroid-Y) takes priority.

---

## 🧭 Open Challenge — Strategy & Logic

`open_challenge.py` + `vision_pipeline_3.py`. No speed PID, no obstacle states, no parking. Servo centre 90°, motor power 85%.

### State Machine

```
INITIALIZE
    │  Wait for any sensor input → init = True, servo to 65°
    ▼
DIRECTION DETECTION (first trigger only)
    │  (tf_h < 70mm AND tf_l > 100mm) OR blue_l  → blue_flag = True (CCW)
    │  (tf_h < 70mm AND tf_r > 100mm) OR orange_l → orange_flag = True (CW)
    ▼
DRIVING LOOP — counter < 12

    Steering priority:
    1. Both outer walls visible:
         err = 320 − ((left_offset + right_offset) / 2)
         servo.setAngle(90 + servo_angle)
    2. Left wall only:  err = outer_wall_left / 2
    3. Right wall only: err = −(640 − outer_wall_right) / 2
    4. Inner wall (counter > 0):
         left only  → correctAngle(heading + 10, 1)
         right only → correctAngle(heading − 10, 1)
    5. Fallback: correctAngle(heading_angle, head, 1)

    Motor: 85% target, smoothed ramp (power×0.01 + prev×0.99)

    TURN TRIGGER
    │  orange_l AND orange_flag AND not trigger → trigger = True
    │  blue_l AND blue_flag AND not trigger → trigger = True
    │  Trigger resets after 2s timeout
    ▼
    TURN EXECUTION (counter_flag=False AND trigger)
    │  Wait for corr < 5° or close_wall / open-side TOF breaks early
    │  → counter++
    │  → heading_angle = update_heading(counter, ...)
    │  → counter_flag = True
    ▼
STOP — counter == 12
    All 4 conditions simultaneously:
    • NOT trigger
    • time since last trigger > 3.5s
    • get_closest_setpoint(head) == heading_angle
    • last_wall.value > 0
    → runMotor(0, 1) → sys.exit(0)
```

### Open Challenge Pseudocode

```
INITIALIZE sensors, servo to 65°
WHILE direction unknown:
    DETECT orange_l or blue_l floor line
    OR check side TOF for open corridor
    SET direction = CW (orange) or CCW (blue)

WHILE counter < 12:
    READ outer wall centroids from camera
    COMPUTE steering error from wall centroids
    APPLY servo correction (PD on pixel error)
    DETECT floor line colour trigger
    IF trigger: counter++, update heading setpoint

CHECK stop conditions (all 4 must be true)
STOP motor
```

---

## 🚧 Obstacle Challenge — Strategy & Logic

### Full State Machine

```
STARTUP
    CameraProcess (P) — OpenCV HSV pipeline
    IMUandEncoder (E) — XIAO UART: heading + encoder counts
    DriveProcess (S)  — main loop, TFmini polled directly

DIRECTION + PARKING SIDE DETECTION
    (tf_l < tf_r AND tf_l > 0) OR outer_wall_left only → orange_flag (CW, parking right)
    (tf_r < tf_l AND tf_r > 0) OR outer_wall_right only → blue_flag (CCW, parking left)

STARTUP MANEUVER (inParkingatStart)
    orange: correctAngle(heading + 60, multiplier=3)
    blue:   correctAngle(heading − 70, multiplier=3)
    Drive forward (ramp: duty×0.001 + prev×0.999) until corr < 2°

DRIVING LOOP — counter < 12

    Block visible:
        Green state1: err = 340 − centr_x
        Green state2: err = 520 − centr_x  (blue+wall: 320/470)
        Red state1:   err = 300 − centr_x_red
        Red state2:   err = 120 − centr_x_red  (orange+wall: 320/170)
        None + one inner wall: err = ±15 nudge
        None + no block: correctAngle(heading ± 5°, 1.5)
        Pink + continue_parking: err = 540−pink_x (right) / 125−pink_x (left)

    Centroid PD: servo_angle = err×kp_s + (Δerr/dt)×kd_s, clamped ±30°
    obstacle_state 1→2: centr_y > 100 (block close)
    obstacle_state 2→1: after 0.08s, or pink/close_wall triggers early

    Turn trigger: orange_l (CW) or blue_l (CCW)
        → counter++, heading_angle updated
        → trigger resets after 2s

    Motor: 90% base, 75% when block visible

LAP FINISH — counter == 12
    Drive to heading setpoint (orange:270°, blue:−270°), time > 1.7s
    Drive until close_wall > 0 (max 0.5s)
    Reverse 3s with correctReverseAngle
    Compute target encoder:
        orange + parking_right: counts + 18200
        orange + parking_left:  counts + 13800
        blue   + parking_right: counts + 13800
        blue   + parking_left:  counts + 18200
    Drive forward until counts ≥ target → stop 2s → lap_finish = True

PRE-PARKING
    orange: heading += 90, blue: heading −= 90
    Reverse until corr < 5°, reverse 1s, reverse while park_wall > 3100
    Forward until park_wall > 3100
    heading ± 95°, reverse until corr < 5° → continue_parking = True

CONTINUE PARKING (parking approach)
    Drive forward at 40%
    Steer: pink visible → follow pink centroid
           else → correctAngle(heading, 1)
    Trigger: last_wall > 1570 AND |heading_err| < 15° AND not pink
           → parking_flag = True

MAIN PARKING
    STATE 1: Reverse until not pink_b
             If last_wall < 1500: forward (counts + 700)
             → STATE 2

    STATE 2: heading −= 90 (right) or += 90 (left)
             Reverse until corr < 5°
             Reverse until pink_b visible
             → STATE 4

    STATE 4: count_thresh = 400 (pink_x ≥ 320) or 600 (pink_x < 320)
             heading_thresh = 60 or 80; PID_thresh = 1.5 or 3.0
             Forward count_thresh counts with correctAngle(heading + heading_thresh)
             Reverse until corr < 8°
             Forward until centr_y_pink > 235  ← visual terminal condition
             Motor stop, servo 95°, sys.exit(0)
```

### Parking Strategy — Why Multi-Stage?

A simple forward drive into the slot fails because the robot always arrives at a slight angle from the final turn. Our 4-state sequence solves this:

- **STATE 1** — Backs out until the pink boundary disappears (exits the approach angle), then optionally drives forward into position
- **STATE 2** — Rotates 90° and reverses until the pink boundary is visible again (robot physically inside the slot)
- **STATE 4** — Forward with heading bias, then straighten, then inch forward until `centr_y_pink > 235` — the pink border filling the camera frame is the terminal condition, independent of encoder count or time

**Why `centr_y_pink > 235`?** When the pink boundary fills the bottom of the camera frame, the robot is fully inside the lot by visual confirmation. This is more reliable than an encoder count, which can vary with wheel slip and battery voltage.

### Obstacle Challenge Pseudocode

```
INITIALIZE sensors, detect direction from side distances
EXECUTE startup maneuver (steer away from wall, straighten)

WHILE counter < 12:
    READ TFmini Plus: tfmini.getTFminiData()
    READ camera: red_b, green_b, centr_x, centr_x_red
    COMPUTE err from block centroid or wall nudge
    APPLY centroid PD to servo
    DETECT floor line trigger → counter++
    IF counter == 12: execute lap-finish routine

COMPUTE parking position from encoder counts
STOP → lap_finish = True

EXECUTE pre-parking maneuver (align heading to slot)
DRIVE forward, follow pink or heading
WAIT for parking_flag (last_wall + heading aligned)

EXECUTE STATE 1 → STATE 2 → STATE 4 parking sequence
CONFIRM by centr_y_pink > 235
STOP
```

---

## 🔄 Engineering Decisions & Iterations

### Decision 1: Sensor Selection — TFmini Plus for Parking

VL53L0X ToF sensors were our first choice for side distance sensing. At close range (<80mm) the 25° FOV caused false readings from floor reflections. We also hit I2C address contention — all VL53L0X sensors boot at `0x29`, requiring careful per-sensor XSHUT sequencing. Any mistake silently corrupted other sensors on the bus.

The TFmini Plus solved both problems — 3.6° laser spot, UART interface (no shared bus), stable at close range. After testing, we found one sensor on the right side is sufficient. The parking lot is always on the outer wall, and the robot's approach always brings the right flank toward it. Front and rear distance sensing was removed entirely — camera black wall zones and floor line colour proved more robust than ToF thresholds at competition speeds.

**Result:** Right side: TFmini Plus (`/dev/ttyAMA1`, read directly in DriveProcess). Front / rear / left: no sensors.

### Decision 2: Motor Driver Upgrade — MDD3A → Vikram-453R6

The MDD3A has no overcurrent protection — a wall collision at speed passes full current straight through. We lost two MDD3A drivers in one testing season. The Vikram-453R6 (DRV8871) adds hardware overcurrent detection, thermal shutdown, and auto-recovery. It's also pin-compatible with the MDD3A — no firmware changes needed.

### Decision 3: Multiprocessing vs. Single-Threaded

Single-threaded development blocked the drive loop for 10–15ms per camera read at 5fps. At 90% PWM the robot travels ~15mm blind per blocked millisecond. `multiprocessing` was chosen over `threading` because the GIL prevents threads from running CPU-bound tasks in parallel. Four OS processes on four Pi 4 cores: camera, IMU/encoder, TOF, and drive.

### Decision 4: Centroid PD vs. Dead-Reckoning for Pillar Avoidance

Last season we maintained an (x, y) position estimate via encoder dead-reckoning. Drift of ±30 units by lap 3 still caused avoidance misses. This season avoidance is driven directly by the pillar's pixel centroid — no positional state, no drift, and target setpoints can be tuned from video review in minutes rather than hours of encoder calibration.

### Decision 5: Parking — Why Visual Terminal Condition?

Earlier parking versions used encoder counts and timeouts as terminal conditions. Both are unreliable — encoder counts vary with wheel slip, and timeouts don't confirm the robot is actually inside. The `centr_y_pink > 235` threshold is a direct visual confirmation from the camera: when the pink boundary fills the bottom of frame, the robot is fully inside. No encoder, no timer needed.

### Potential Future Improvements

- Motor with built-in encoder to simplify hardware
- Auto `SPEED_SCALE` calibration from first run log
- Rear camera or second TFmini for reverse safety
- Custom carrier PCB to clean up wiring
- Online PID gain scheduling based on lap time (encoder data already available)

---

## 📹 Performance Videos

### Open Challenge

Open Challenge (https://www.youtube.com/watch?v=8WccRAMPBGA)

### Obstacle Challenge

Obstacle Challenge (https://www.youtube.com/watch?v=rnG7ssZLk40)

---

## 🌐 GitHub Utilization

We use GitHub as our central platform for version control, documentation, and public transparency. Our workflow: develop locally, commit at meaningful milestones (completed state machine, fixed parking detection, validated motor driver swap), and update documentation alongside code so the repo always reflects the actual robot.

**Key development milestones:**
- First working chassis + wiring (Version 1)
- HSV pipeline replacing Edge TPU (Version 2)
- TFmini Plus integration + parking state machine
- Multiprocessing architecture finalized
- Speed PID implementation and calibration
- Nationals-ready documentation pass

**Commit philosophy:** Each commit represents a tested, working state of the robot. We don't commit broken intermediate states — every push to `main` is something the robot could actually run in competition.

**Documentation standards:**
- ✅ Every hardware change reflected in README on the same day
- ✅ Every code change explained in comments, not just committed
- ✅ Run logs included in `/logs/` for traceability
- ✅ Wiring diagram updated whenever hardware changes
- ✅ All placeholder values filled in before nationals submission

---

## 📜 License

This project is open source. Other teams are encouraged to read, learn from, and build on our documentation and code. The modular architecture and detailed decision rationale are intentionally written to make replication straightforward.

If you build on our work, please keep it open source and credit Team Glitch, WRO 2026.

---

## 🛠️ How to Build & Deploy

### Step 1 — Chassis

Files in `models/`:

```
models/
├── 3D prints/
│   ├── all part 3d print file.3mf       # Full print project
│   ├── new camera mount.STL             # 10° downward tilt
│   ├── long stick.STL                   # Sensor mast
│   ├── long stick mount.STL             # Mast base
│   ├── front cover.STL
│   ├── battery 1.STL
│   ├── spacer with tf mount.STL
│   └── tf mini mount horizontal.STL    # TFmini Plus right-side bracket
└── STEP/
    ├── WRO FE Car complete CAD.STEP     # Full assembly reference
    ├── chassis_Polycarbonate_6mm thickness_qty1pc.STEP
    └── electronics Mount_3mm polycarbonate_ qty 1.STEP
```

Chassis and tray are laser/CNC-cut, not printed. Print settings: PETG, 0.2mm layer, 40% gyroid, 4 perimeters. Supports for camera mount and mast base only.

### Step 2 — Assembly

1. Cut chassis (6mm poly) and electronics tray (3mm poly).
2. Mount Johnson 900RPM motor. Mount external encoder on output shaft, route cable to XIAO.
3. Install DS3235 servo + Parallel steering linkage. Inner wheel must turn sharper than outer at full lock.
4. Mount sensor mast at front-centre.
5. Mount TFmini Plus on right flank at 60mm height using `tf mini mount horizontal.STL`, perpendicular to travel.
6. Mount camera (`new camera mount.STL`) — fixed 10° tilt, no adjustment.
7. Mount electronics tray. Install Pi, XIAO, Vikram-453R6.

### Step 3 — Wiring

See `schemes/wiring_diagram.png`. Critical rules:
- BNO085 on XIAO 3V3 only — never Pi 3V3
- TFmini Plus VCC = 5V buck; TX is 3.3V-compatible, direct to Pi UART RX
- Vikram VM = 12V direct from LiPo — never through the 5V buck
- Motor and encoder wires on opposite chassis sides

### Step 4 — Flash XIAO

1. Arduino IDE ≥2.0, board URL: `https://files.seeedstudio.com/arduino/package_seeeduino_boards_index.json`
2. Install: `Adafruit BNO08x`, `Adafruit Unified Sensor`
3. Open `src/xiao/imu_encoder.ino`, select **XIAO ESP32C3**, upload.

### Step 5 — Raspberry Pi Setup

Enable UART in `/boot/firmware/config.txt`:
```
dtoverlay=uart2
```

```bash
sudo apt update && sudo apt install -y python3-pip pigpio python3-pigpio ffmpeg i2c-tools
pip3 install opencv-python pyserial RPi.GPIO numpy
```

Test TFmini Plus:
```python
import serial, time
ser = serial.Serial("/dev/ttyAMA1", 115200, timeout=0.1)
while True:
    data = ser.read(9)
    if len(data) == 9 and data[0] == 0x59 and data[1] == 0x59:
        dist_cm = data[2] + data[3] * 256
        print(f"Distance: {dist_cm} cm")
    time.sleep(0.05)
```

XIAO udev alias (`/etc/udev/rules.d/99-wro.rules`):
```
SUBSYSTEM=="tty", ATTRS{idVendor}=="XXXX", ATTRS{idProduct}=="YYYY", SYMLINK+="XIAO_USB"
```

### Step 6 — Configure Gains

```json
{
  "kp": 0.55, "kd": 0.0025, "ki": 0,
  "kp_s": 0.05, "kd_s": 0.0000,
  "kp_o": 1.5, "kd_o": 0.5,
  "kp_v": 0.008, "ki_v": 0.0, "kd_v": 0.00,
  "SPEED_SCALE": 7343.37
}
```

Set `SPEED_SCALE` to 0 until you calibrate it from run logs. File hot-reloads every 0.5s — no restart needed.

### Step 7 — Run

```bash
sudo python3 obstacle_3.py    # Obstacle Challenge
sudo python3 open_2.py # Open Challenge
```

Logs: `/home/pi/wro_logs/logs/`. Kill switch: GPIO6.

### Code Structure

```
WRO_2026/
├── versionTest/
│   ├── obstacle_3.py              # Obstacle — 4-process
│   ├── open_2.py          # Open — 4-process
│   ├── vision_pipeline_new.py     # HSV pipeline — obstacle
│   ├── vision_pipeline_3.py       # HSV pipeline — open
│   ├── TFmini.py                  # TFmini Plus UART reader
│   ├── Encoder.py                 # Dead-reckoning (open challenge)
│   ├── Servo.py                   # Servo abstraction (pigpio)
│   ├── build_video.py             # Post-run MP4 reconstruction
│   └── gains.json                 # Hot-reloadable PID gains
├── src/xiao/imu_encoder.ino       # XIAO firmware
├── models/
│   ├── 3D prints/
│   └── STEP/
├── schemes/wiring_diagram.png
└── v-photos/
```

---

## GitHub Commit Dates
This table shows the dates of the 3 main commits we have made to the GitHub, and how far they were from the National Competition.

|Commit No.|Date|Time before nationals|
|-|-|-|
|1|June 18 2026|14 days|
|2|July 20 2026|37 days|
|3|Aug 12 2026|69 days|

**Team Glitch — WRO 2026 Future Engineers — India Nationals**

*Documentation last updated: August 2026*

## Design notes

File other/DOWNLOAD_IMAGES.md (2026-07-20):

# 📥 Component Image Download Guide

Replace each placeholder SVG with a real photo downloaded from the links below.
Save each image into the `other/` folder with the exact filename shown.

| File to create | Download source |
|---|---|
| `rplidar_c1.jpg` | https://robu.in/product/rplidar-c1m1-r2-portable-tof-laser-scanner-kit-12m-range/ |
| `tfmini_plus.jpg` | https://robu.in/product/tfmini-plus-lidar-distance-sensor-for-drones-uav-uas-robots-12m/ |
| `bno055.jpg` | https://robu.in/product/adafruit-9-dof-absolute-orientation-imu-fusion-breakout-bno055-stemma-qt-qwiic/ |
| `camera_ds_u02.jpg` | https://www.amazon.in/HIKVISION-DS-U02-Distortion-Adjustment-Conferencing/dp/B0929FSQ2J |
| `raspberry_pi4.jpg` | https://robu.in/product/raspberry-pi-4-model-b-with-4-gb-ram/ |
| `arduino_mega.jpg` | https://robu.in/product/mega-2560-atmega2560-16au-board-without-usb-cable/ |
| `johnson_motor.jpg` | https://robu.in/product/grade-a-quality-orange-12v-600-rpm-johnson-geared-dc-motor/ |

### How to save an image from robu.in:
1. Open the link above in your browser
2. Right-click on the main product image
3. Select "Save image as..."
4. Save with the exact filename shown in the table above
5. Place it in the `other/` folder of your repo

### Robot Photos needed (place in `v-photos/` folder):
- `front.jpg`
- `rear.jpg`
- `left.jpg`
- `right.jpg`
- `top.jpg`
- `bottom.jpg`
- `labeled.jpg` (with component labels overlaid)

### Team Photos needed (place in `t-photos/` folder):
- `team_official.jpg`
- `team_fun.jpg`

### Wiring Diagram needed (place in `schemes/` folder):
- `wiring_diagram.jpg`

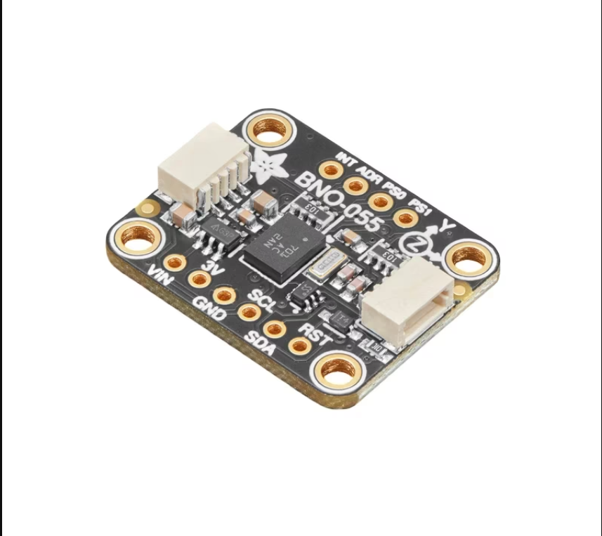
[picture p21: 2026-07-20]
other/bno055.png

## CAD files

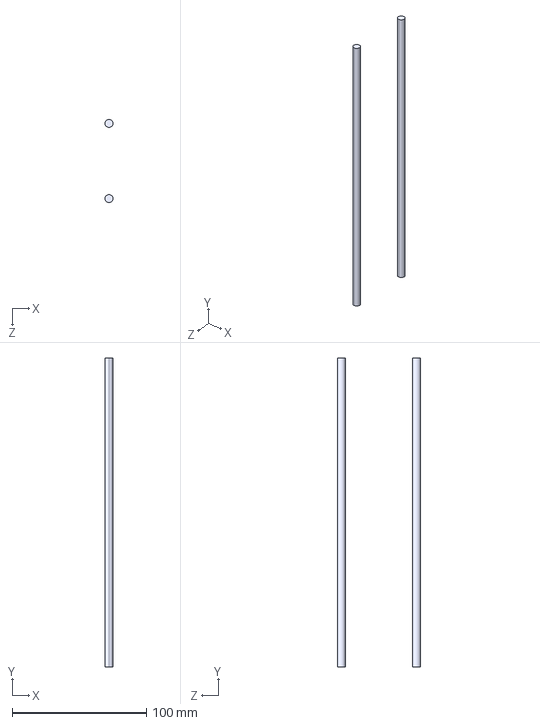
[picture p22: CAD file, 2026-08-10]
models/STEP/chassis body shaft_ AL 2pc.STEP
6.00 x 230.0 x 62.0 mm

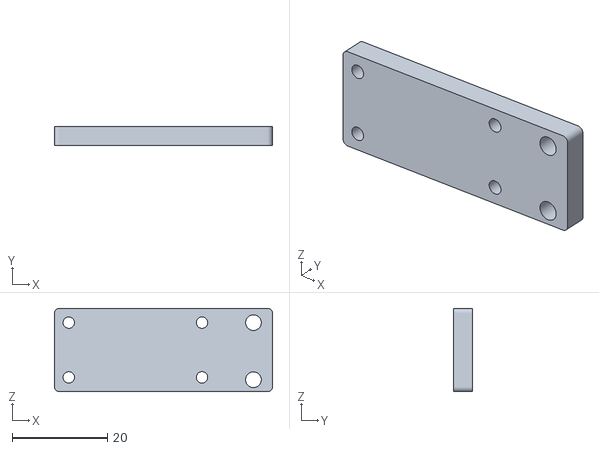
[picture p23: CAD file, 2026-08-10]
models/STL/side mount tf mini mount.STL
45.8 x 4.00 x 17.5

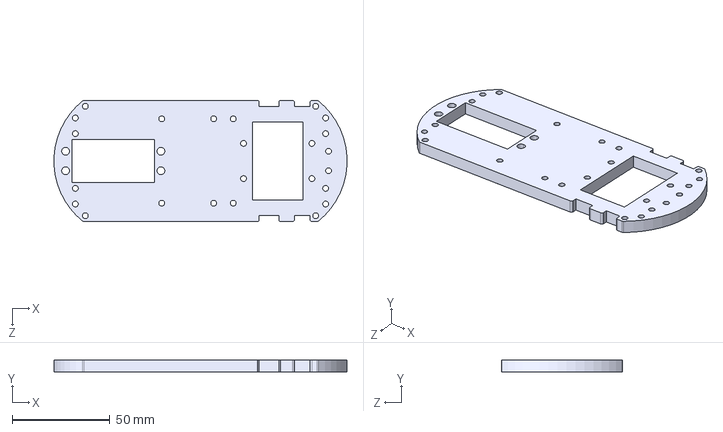
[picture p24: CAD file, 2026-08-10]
models/STEP/chassis body_6mm poly_1pc.STEP
149.9 x 6.00 x 62.0 mm

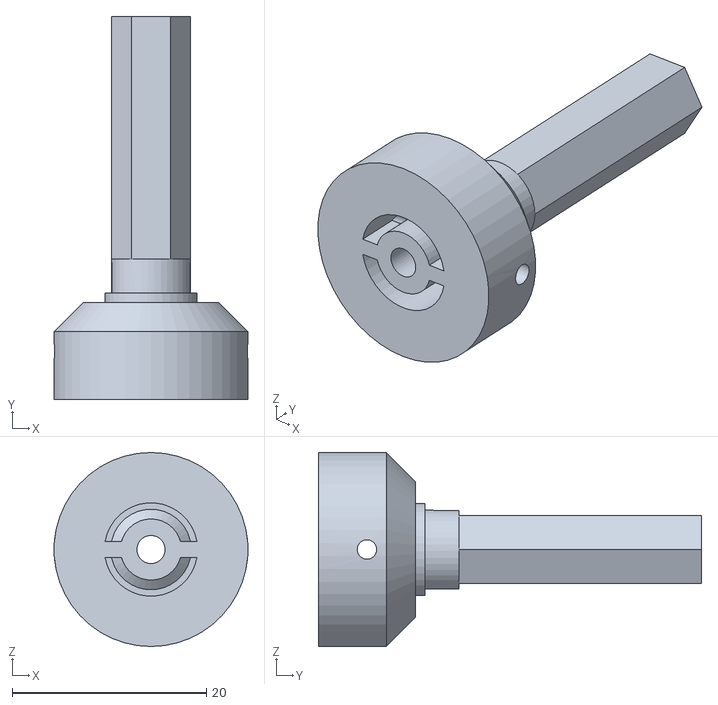
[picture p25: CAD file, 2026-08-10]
models/STL/back wheel.STL
20.0 x 39.5 x 20.0

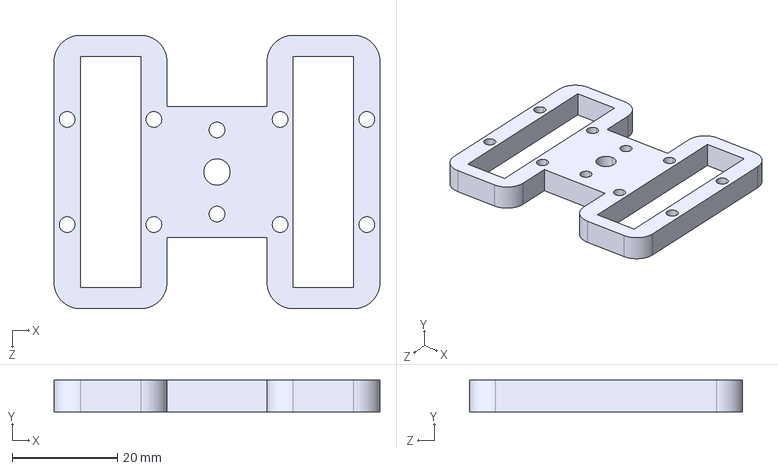
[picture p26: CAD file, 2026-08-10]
models/STEP/poly_6mm_1pc_front axel support.STEP
62.0 x 6.00 x 52.0 mm

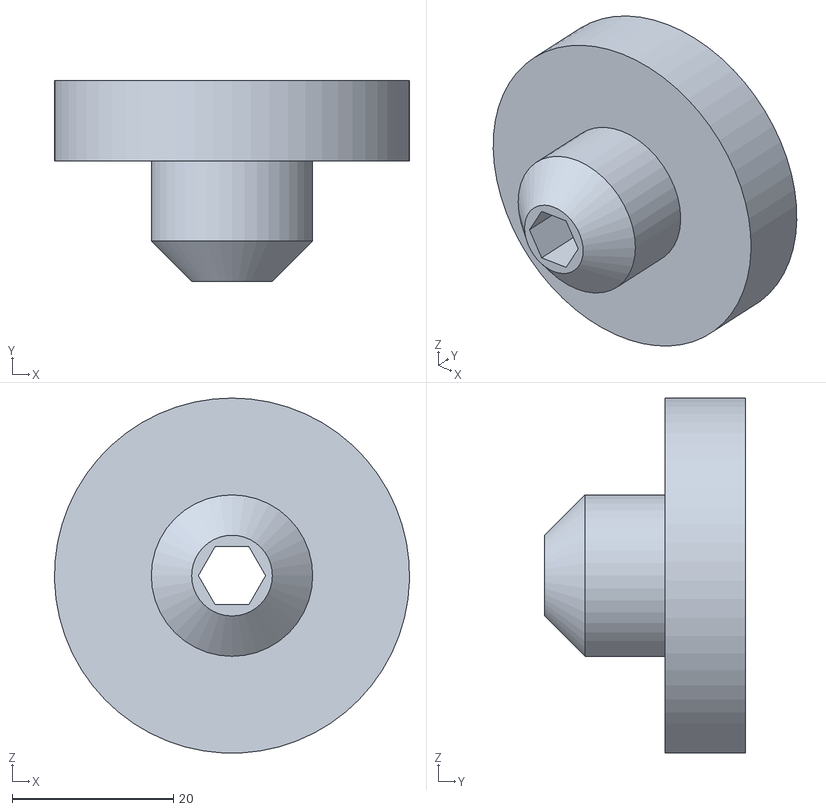
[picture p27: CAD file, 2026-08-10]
models/STL/new front wheel.STL
44.0 x 24.9 x 44.0

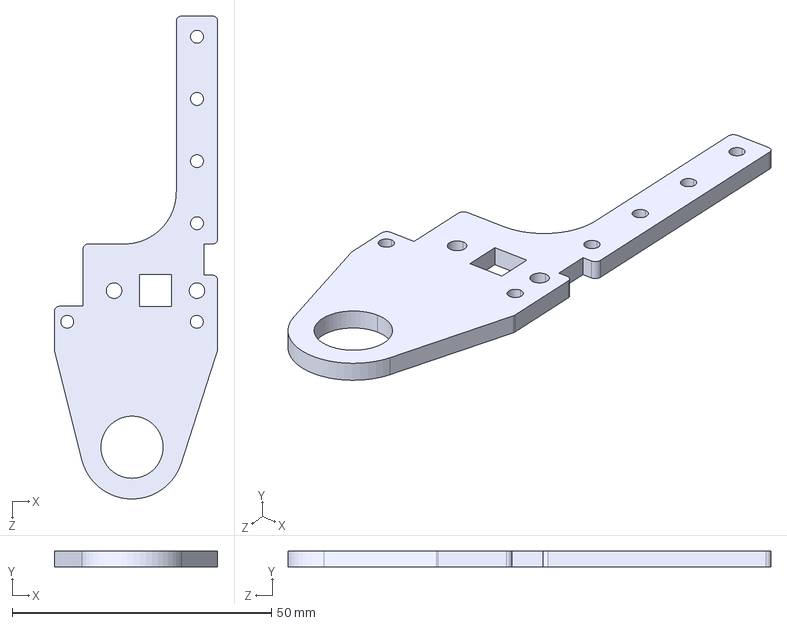
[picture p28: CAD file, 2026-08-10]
models/STEP/side bearing mount_ 3mm AL_ 2pc.STEP
31.5 x 3.00 x 93.2 mm

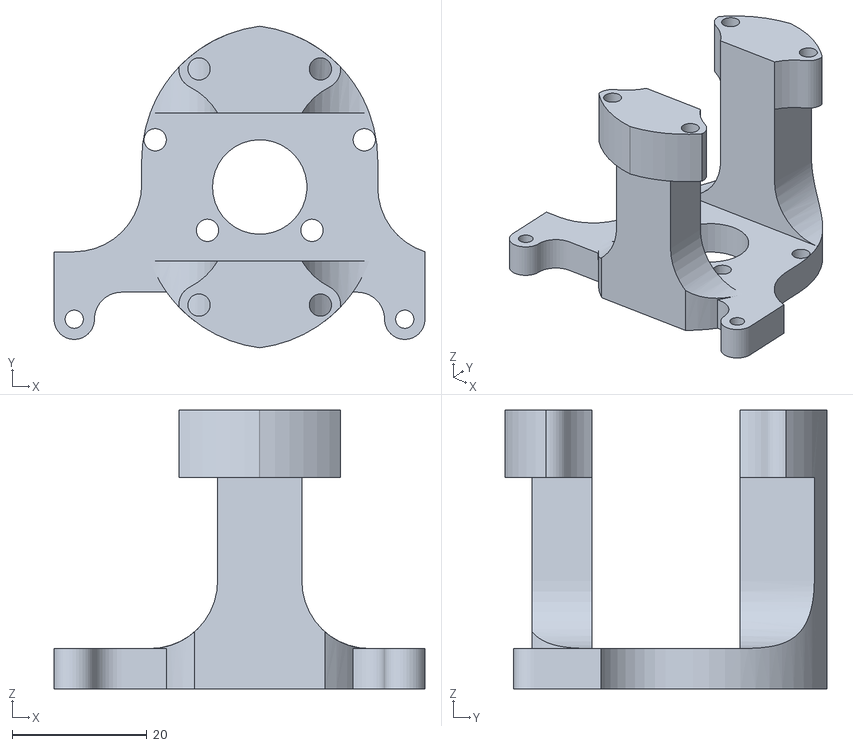
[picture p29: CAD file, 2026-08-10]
models/STL/dc motor mount.STL
55.0 x 47.7 x 41.3

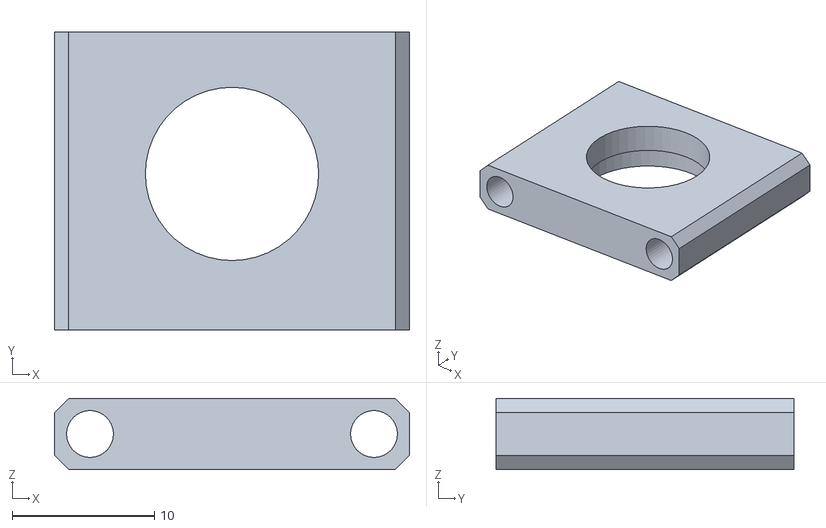
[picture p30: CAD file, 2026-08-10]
models/STL/front bearing_6_12_holder.STL
25.0 x 21.0 x 5.00

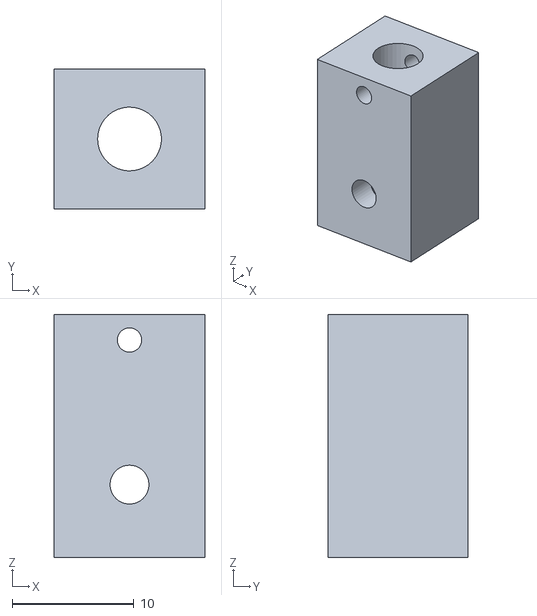
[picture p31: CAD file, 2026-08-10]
models/STL/dc motor coupling.STL
12.4 x 11.5 x 20.0

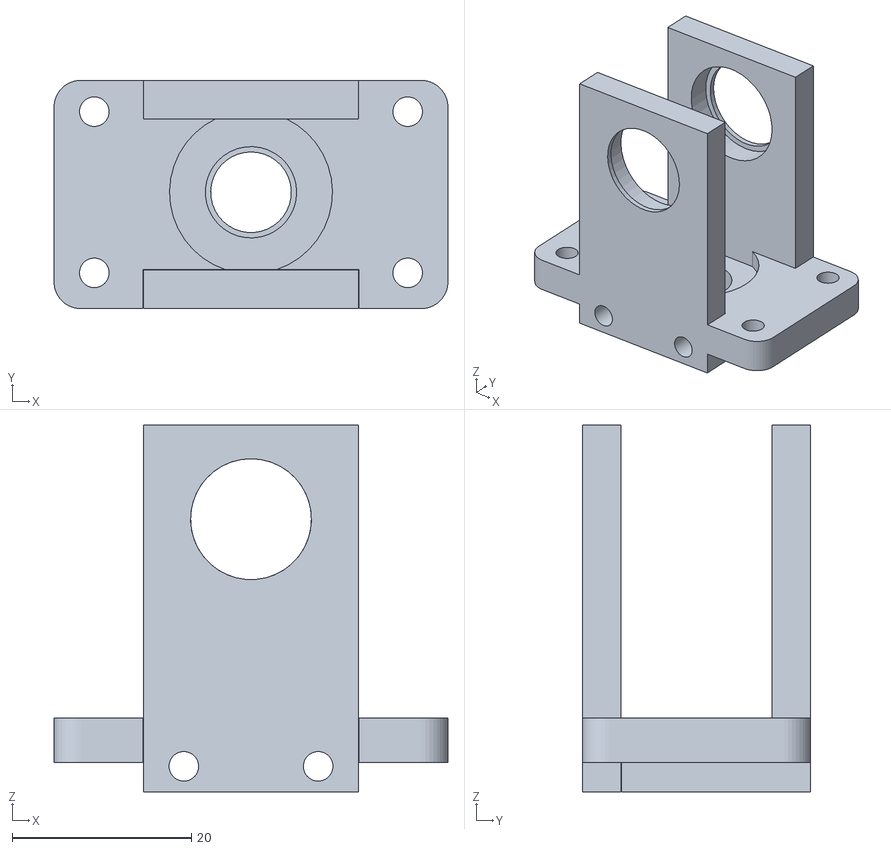
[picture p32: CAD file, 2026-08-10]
models/STL/back Gear Mount.STL
44.0 x 25.5 x 41.0

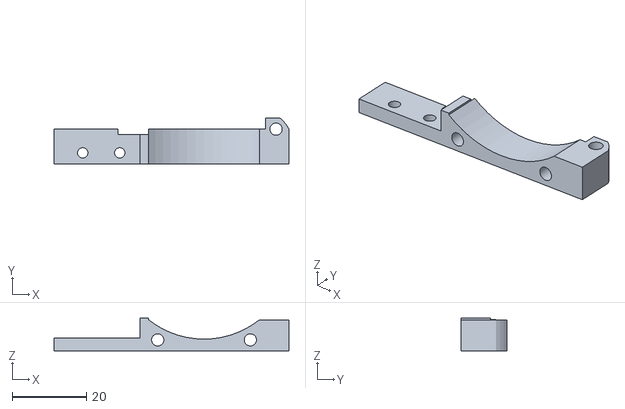
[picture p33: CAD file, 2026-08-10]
models/STL/side bearing plate mount.STL
63.4 x 12.4 x 8.90

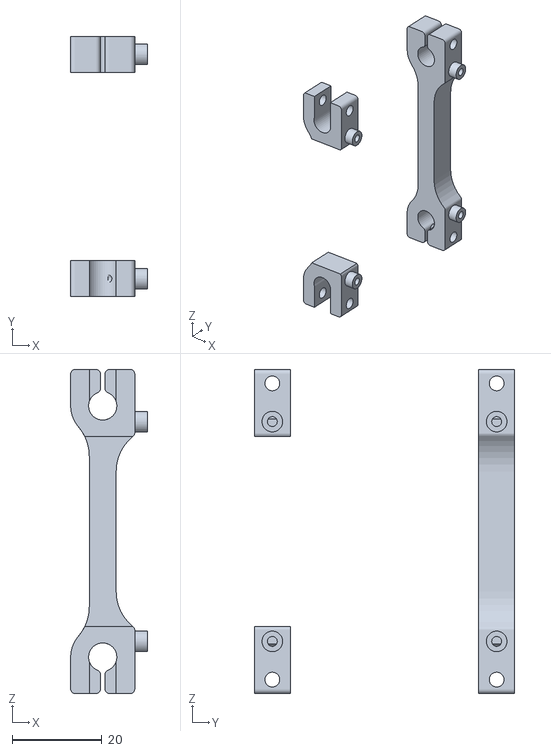
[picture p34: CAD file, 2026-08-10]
models/STL/back rpi mount.STL
17.1 x 58.0 x 72.2

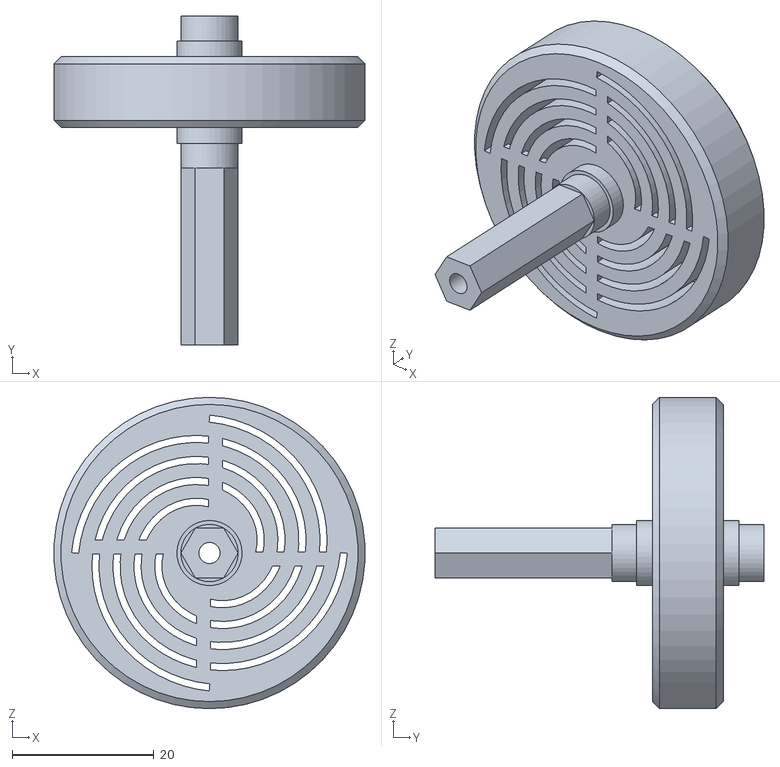
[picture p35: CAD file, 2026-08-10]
models/STL/Front wheel.STL
43.9 x 46.5 x 44.0

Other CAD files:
models/STL/top camera mount.STL

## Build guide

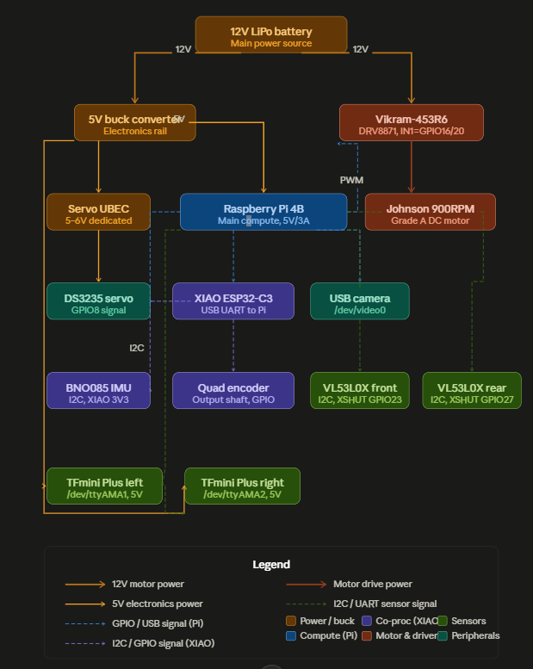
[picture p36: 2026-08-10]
schemes/wiring_diagram_2.png

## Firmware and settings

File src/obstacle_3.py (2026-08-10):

import time
import os
from build_video import _build_video

os.system("sudo pkill pigpiod")
time.sleep(2)
os.system("sudo pigpiod -x -1")  # -x -1 = allow every GPIO
time.sleep(3)  # give the daemon time to come up
from datetime import datetime
import numpy as np
import cv2
import subprocess
import sys
import logging
import multiprocessing
import pigpio
import math
from Encoder import EncoderCounter
from Servo import Servo
import serial
import traceback
from collections import deque
from vision_pipeline_new import VisionPipeline, FrameSmoother, USE_LAB, SMOOTH_N, FRAME_WIDTH, FRAME_HEIGHT, FRAME_MIDPOINT_X
from vl53l0x import VL53L0XArray
import json
from TFmini import TFmini

GAINS_FILE = "/home/pi/WRO_2026/versionTest/gains.json"
GAINS_CHECK_INTERVAL = 0.5  # seconds between file checks — cheap, don't check every tick
_gains_last_check = 0.0
_gains_mtime = 0.0


"""{
  "kp": 0.6,
  "kd": 0.01,
  "ki": 0,
  "kp_s": 0.06,
  "kd_s": 0.8,
  "kp_v": 0.8,
  "ki_v": 0.0,
  "kd_v": 0.05,
  "SPEED_SCALE": 40.0
}"""

kp = 0.6
kd = 0.01
ki = 0
kp_s = 0.06
kd_s = 0.8


def load_gains_if_changed():
	global kp, kd, ki, kp_s, kd_s, kp_v, ki_v, kd_v, SPEED_SCALE, _gains_last_check, _gains_mtime

	now = time.time()
	if now - _gains_last_check < GAINS_CHECK_INTERVAL:
		return
	_gains_last_check = now

	try:
		mtime = os.path.getmtime(GAINS_FILE)
		if mtime == _gains_mtime:
			return  # file hasn't changed since last load
		with open(GAINS_FILE) as f:
			gains = json.load(f)
		kp = gains.get("kp", kp)
		kd = gains.get("kd", kd)
		ki = gains.get("ki", ki)
		kp_s = gains.get("kp_s", kp_s)
		kd_s = gains.get("kd_s", kd_s)
		kp_v = gains.get("kp_v", kp_v)
		ki_v = gains.get("ki_v", ki_v)
		kd_v = gains.get("kd_v", kd_v)
		SPEED_SCALE = gains.get("SPEED_SCALE", SPEED_SCALE)
		_gains_mtime = mtime
		print(f"[gains] reloaded: kp={kp} kd={kd} ki={ki} kp_s={kp_s} kd_s={kd_s} kp_v={kp_v} ki_v={ki_v} kd_v={kd_v} SPEED_SCALE={SPEED_SCALE}")
	except (FileNotFoundError, json.JSONDecodeError, ValueError) as e:
		print(f"[gains] reload skipped ({e}) — keeping current values")


os.makedirs("/home/pi/WRO_2026/logs", exist_ok=True)
log_file = open(f"/home/pi/wro_logs/logs/obstacle_{datetime.now().strftime('%Y-%m-%d_%H-%M-%S')}.log", "w")


class Tee:
	def __init__(self, *streams):
		self.streams = streams
		self._counts = 0

	def write(self, data):
		for s in self.streams:
			s.write(data)
			# s.flush()
			self._counts += 1
		if self._counts % 20 == 0:
			self.flush()

	def flush(self):
		for s in self.streams:
			s.flush()


sys.stdout = Tee(sys.stdout, log_file)
sys.stderr = Tee(sys.stderr, log_file)
# ─────────────────────────────────────────────────────────────────────────────
# PINS
# ─────────────────────────────────────────────────────────────────────────────

RX_Head = 23
RX_Left = 17
RX_Right = 25
RX_Back = 27
button_pin = 5
switch_pin = 6
exit_pin = 7
servo_pin = 8
blue_led = 26
red_led = 13
green_led = 6
reset_pin = 19

# MDD3A Motor Driver pins
PIN_A = 16  # MDD3A M1A
PIN_B = 20  # MDD3A M1B

# ─────────────────────────────────────────────────────────────────────────────
# INITIALIZATION
# ─────────────────────────────────────────────────────────────────────────────

process = None
# ser = serial.Serial("/dev/XIAO_USB", 115200)
print("created uart")


# VL53L0X distance sensor array (replaces TFmini)
# tof = VL53L0XArray()
# tof.init()

# log = logging.getLogger("WRO")
rplidar = [None] * 360
previous_distance = 0
dist_0 = dist_90 = dist_270 = angle = 0
lidar_front = lidar_left = lidar_right = 0

# ─────────────────────────────────────────────────────────────────────────────
# MULTIPROCESSING VARIABLES
# ─────────────────────────────────────────────────────────────────────────────

counts = multiprocessing.Value("i", 0)
fps_m = multiprocessing.Value("f", 0.0)

color_b = multiprocessing.Value("b", False)
red_b = multiprocessing.Value("b", False)
green_b = multiprocessing.Value("b", False)
pink_b = multiprocessing.Value("b", False)
centr_y = multiprocessing.Value("f", 0.0)
centr_x = multiprocessing.Value("f", 0.0)
centr_y_red = multiprocessing.Value("f", 0.0)
centr_x_red = multiprocessing.Value("f", 0.0)
centr_x_pink = multiprocessing.Value("f", 0.0)
centr_y_pink = multiprocessing.Value("f", 0.0)
head = multiprocessing.Value("f", 0.0)
previous_angle = multiprocessing.Value("d", 0.0)
orange_l = multiprocessing.Value("b", False)
blue_l = multiprocessing.Value("b", False)
wall_left = multiprocessing.Value("d", 0.0)
wall_right = multiprocessing.Value("d", 0.0)
outer_wall_left = multiprocessing.Value("d", 0.0)
outer_wall_right = multiprocessing.Value("d", 0.0)


close_wall = multiprocessing.Value("d", 0.0)
park_wall = multiprocessing.Value("d", 0.0)
last_wall = multiprocessing.Value("d", 0.0)
last_wall_2 = multiprocessing.Value("d", 0.0)

time_video = multiprocessing.Value("d", 0.0)

left_a = multiprocessing.Value("f", 0.0)
right_a = multiprocessing.Value("f", 0.0)
red_area = multiprocessing.Value("b", False)
green_area = multiprocessing.Value("b", False)


centr_y_close = multiprocessing.Value("f", 0.0)
centr_x_close = multiprocessing.Value("f", 0.0)
centr_y_red_close = multiprocessing.Value("f", 0.0)
centr_x_red_close = multiprocessing.Value("f", 0.0)

# near your other multiprocessing.Value declarations in __main__
switch_state = multiprocessing.Value("b", False)

# ─────────────────────────────────────────────────────────────────────────────
# SHARED MEMORY FOR TOF SENSOR READINGS (so DriveProcess can read them)
# ─────────────────────────────────────────────────────────────────────────────

tof_front = multiprocessing.Value("d", 0.0)
tof_left = multiprocessing.Value("d", 0.0)
tof_right = multiprocessing.Value("d", 0.0)
tof_rear = multiprocessing.Value("d", 0.0)


# ─────────────────────────────────────────────────────────────────────────────
# PID VARIABLES
# ─────────────────────────────────────────────────────────────────────────────

currentAngle = 0
error_gyro = 0
prevErrorGyro = 0
totalErrorGyro = 0
correcion = 0
totalError = 0
prevError = 0
prevErrorServo = 0
totalErrorServo = 0
prev_loop_time = time.time()

kp_e = 3
ki_e = 0
kd_e = 40

corr = 0
corr_pos = 0

# ── SPEED PID (closed-loop, compensates for battery voltage sag) ──────────
# Corrects motor duty cycle so actual wheel speed (from encoder counts)
# tracks a target speed derived from the requested 'power' percentage,
# regardless of battery voltage sag. Direction-aware: encoder counts
# DECREASE during reverse on this robot, so the delta is sign-flipped
# for direction == 0. Auto-resets whenever direction flips, since forward
# and reverse have different dynamics and stale state would cause a kick.
kp_v = 0.8
ki_v = 0.0
kd_v = 0.05
SPEED_SCALE = 40.0  # counts/sec at duty=100 on a fresh battery — CALIBRATE from logs

prev_counts_speed = 0
prev_error_speed = 0
total_error_speed = 0
speed_duty = 0.0
prev_loop_time_speed = time.time()
prev_direction_speed = None  # tracks last direction so we auto-reset on flip


# ─────────────────────────────────────────────────────────────────────────────
# HELPERS
# ─────────────────────────────────────────────────────────────────────────────


def is_switch_off_and_stop(pwm):
	"""Returns True if the kill switch has been flipped off.
	As a side effect, immediately cuts motor PWM so the robot
	doesn't coast/keep driving while the outer loop catches up."""
	if pwm.read(switch_pin) == 0:
		pwm.set_PWM_dutycycle(PIN_A, 0)
		pwm.set_PWM_dutycycle(PIN_B, 0)
		return True
	return False


def get_closest_setpoint(heading: float) -> int:
	setpoints = [0, 90, 180, 270]

	heading = heading % 360

	def angular_diff(a, b):
		diff = abs(a - b) % 360
		return min(diff, 360 - diff)

	return min(setpoints, key=lambda sp: angular_diff(heading, sp))


def map_range(value, in_min, in_max, out_min, out_max):
	return (value - in_min) * (out_max - out_min) / (in_max - in_min) + out_min


def update_heading(counter: int, heading_angle: float, blue: bool, orange: bool) -> float:
	if blue:
		return -((90 * counter) % 360)
	elif orange:
		return (90 * counter) % 360
	return heading_angle


def map_range(value, in_min, in_max, out_min, out_max):
	return (value - in_min) * (out_max - out_min) / (in_max - in_min) + out_min


def correctWall(setPoint_distance, dist, sp_h, imu_h, orange, blue, pink_l, counter, left, right):
	error_d = prevError_d = totalError_d = correction_d = 0

	if right:
		error_d = dist - setPoint_distance
		print(f"right error: {error_d}")
	elif left:
		error_d = setPoint_distance - dist
		print(f"left error: {error_d}")

	pTerm = 2.5 * error_d
	dTerm = 0 * (error_d - prevError_d)
	totalError_d += error_d
	iTerm = 0 * totalError_d
	correction = pTerm + iTerm + dTerm
	correction = max(-40, min(40, correction))

	"""if dist < 30 and setPoint_distance == 35:
		print("correction 0 35")
		correction = 0
	if setPoint_distance == 60 and dist < 20:
		print("correction 0 60")
		correction = 0
	if setPoint_distance == 45 and dist < 20:
		print("correction 0 is 45")
		correction = 0"""

	print(f"dist is {dist}")
	prevError_d = error_d
	if counter % 4 == pink_l:
		correctAngle(sp_h + correction, imu_h, 1)
	else:
		correctAngle(sp_h + correction, imu_h, 1.8)


def correctAngle(setPoint_gyro, heading, multiplier):
	global corr, prevErrorGyro, totalErrorGyro, prev_loop_time, kp, kd
	error_gyro = correction = 0
	now = time.time()
	dt = now - prev_loop_time
	dt = max(dt, 1e-3)  # avoid divide-by-zero
	dt = min(dt, 0.2)  # clamp so one long stall doesn't spike the derivative
	prev_loop_time = now
	error_gyro = heading - setPoint_gyro
	if error_gyro > 180:
		error_gyro -= 360
	corr = error_gyro

	pTerm = kp * error_gyro * multiplier
	dTerm = kd * ((error_gyro - prevErrorGyro) / dt)
	totalErrorGyro += error_gyro
	iTerm = ki * totalErrorGyro
	correction = pTerm + iTerm + dTerm

	if multiplier == 3:
		correction = max(-45, min(45, correction))
	else:
		correction = max(-25, min(25, correction))

	prevErrorGyro = error_gyro
	servo.setAngle(95 - correction)


def correctReverseAngle(setPoint_gyro, heading, multiplier):
	global corr, prev_loop_time, kp, kd
	error_gyro = prevErrorGyro = totalErrorGyro = correction = totalError = prevError = 0
	now = time.time()
	dt = now - prev_loop_time
	dt = max(dt, 1e-3)  # avoid divide-by-zero
	dt = min(dt, 0.2)  # clamp so one long stall doesn't spike the derivative
	prev_loop_time = now
	error_gyro = heading - setPoint_gyro
	if error_gyro > 180:
		error_gyro -= 360
	corr = error_gyro

	pTerm = kp * error_gyro * multiplier
	dTerm = kd * ((error_gyro - prevErrorGyro) / dt)
	totalErrorGyro += error_gyro
	iTerm = ki * totalErrorGyro
	correction = pTerm + iTerm + dTerm

	if multiplier == 3:
		correction = max(-45, min(45, correction))
	else:
		correction = max(-25, min(25, correction))

	prevErrorGyro = error_gyro
	servo.setAngle(95 + correction)


def normalize_angle(angle, blue, orange, lane):
	if blue:
		return angle + 360 if angle < 180 and lane == 0 else angle
	elif orange:
		return angle - 360 if angle > 180 and lane == 0 else angle


def resetSpeedPID(counts_value):
	"""Clears speed-PID integrator/derivative/output state. Call this
	whenever the target speed jumps discontinuously (e.g. a parking STATE
	transition) so stale error from the previous setpoint doesn't cause
	a kick. Direction flips reset automatically inside correctSpeed."""
	global prev_error_speed, total_error_speed, speed_duty, prev_counts_speed, prev_loop_time_speed
	prev_error_speed = 0.0
	total_error_speed = 0.0
	speed_duty = 0.0
	prev_counts_speed = counts_value
	prev_loop_time_speed = time.time()


def correctSpeed(target_power_pct, counts_value, direction):
	"""
	Closed-loop speed control, direction-aware. Standard positional PID:
	output duty = baseline power + PID correction, recomputed fresh each
	call — NOT accumulated tick-over-tick (that was the bug).
	direction: 1 = forward, 0 = reverse. Encoder counts DECREASE during
	reverse on this robot, so raw delta is sign-flipped for direction==0.
	Auto-resets on direction change.
	"""
	global prev_counts_speed, prev_error_speed, total_error_speed
	global prev_loop_time_speed, prev_direction_speed
	global kp_v, ki_v, kd_v, SPEED_SCALE

	if direction != prev_direction_speed:
		resetSpeedPID(counts_value)
		prev_direction_speed = direction
		return target_power_pct   # first call after flip — start at baseline, not 0

	now = time.time()
	dt = now - prev_loop_time_speed
	dt = max(dt, 1e-3)
	dt = min(dt, 0.2)
	prev_loop_time_speed = now

	raw_delta = counts_value - prev_counts_speed
	prev_counts_speed = counts_value

	actual_cps = (raw_delta / dt) if direction == 1 else (-raw_delta / dt)

	target_cps = target_power_pct * SPEED_SCALE / 100.0
	error = target_cps - actual_cps

	total_error_speed += error * dt
	total_error_speed = max(-500, min(500, total_error_speed))  # anti-windup

	derivative = (error - prev_error_speed) / dt
	prev_error_speed = error

	correction = kp_v * error + ki_v * total_error_speed + kd_v * derivative
	duty = target_power_pct + correction   # baseline + correction, computed fresh
	duty = max(0.0, min(100.0, duty))

	return duty


def driveAtSpeed(pwm, target_power_pct, direction, counts_value):
	"""One-line drop-in replacement for runMotor(pwm, power, direction)
	that closes the loop on wheel speed via correctSpeed()."""
	duty = correctSpeed(target_power_pct, counts_value, direction)
	runMotor(pwm, duty, direction)
	return duty


def runMotor(pwm, speed, direction):
	"""
	MDD3A Truth Table (pigpio):
	  Forward  (direction=1) → PIN_A=PWM, PIN_B=0
	  Backward (direction=0) → PIN_A=0,   PIN_B=PWM
	  Stop     (speed=0)     → PIN_A=0,   PIN_B=0
	"""
	duty = int(max(0.0, min(100.0, speed)) * 2.55)  # 0–100 → 0–255
	if direction == 1:  # forward
		pwm.set_PWM_dutycycle(PIN_B, 0)
		pwm.set_PWM_dutycycle(PIN_A, duty)
	elif direction == 0:  # backward
		pwm.set_PWM_dutycycle(PIN_A, 0)
		pwm.set_PWM_dutycycle(PIN_B, duty)
	else:  # brake / stop
		pwm.set_PWM_dutycycle(PIN_A, 0)
		pwm.set_PWM_dutycycle(PIN_B, 0)


def TOFProcess(tof_front, tof_left, tof_right, tof_rear):
	"""
	Dedicated process for reading VL53L0X sensors.
	Writes latest values into shared memory at full speed.
	DriveProcess reads from shared memory — no blocking waits.
	"""
	print("TOF Process started")
	sensor = VL53L0XArray()
	sensor.init()

	try:
		while True:

			readings = sensor.all()
			time.sleep(0.01)
			# Clamp negatives to 0 for easier comparisons in DriveProcess
			tof_front.value = max(readings["front"], 0)
			tof_left.value = max(readings["left"], 0)
			tof_right.value = max(readings["right"], 0)
			tof_rear.value = max(readings["rear"], 0)
	except Exception as e:
		print(f"TOF Process exception: {e}")
	finally:
		sensor.close()
		print("TOF Process stopped")


# ─────────────────────────────────────────────────────────────────────────────
# PROCESS 1 — Live_Feed  (vision — HSV pipeline)
# ─────────────────────────────────────────────────────────────────────────────


def _serialize_detections(detections):
	out = {}
	for color, dets in detections.items():
		out[color] = []
		for d in dets:
			simplified = cv2.approxPolyDP(d["contour"], 2.0, True)
			out[color].append({"contour": simplified.reshape(-1, 2).tolist(), "area": float(d["area"]), "centroid": [int(d["centroid"][0]), int(d["centroid"][1])], "label": d["label"], "zone": d["zone"]})
	return out
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

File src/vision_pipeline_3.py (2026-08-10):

"""
vision_pipeline.py
------------------
All OpenCV / colour-detection logic for WRO 2025 Obstacle Challenge.
Import into the main file; never run directly.

Usage:
    from vision_pipeline import VisionPipeline, FrameSmoother

ROI Layout (640x360 frame)
--------------------------
Detection only runs on the frame slice from y=100 downward (_GLOBAL_Y_OFFSET).
The main_blocks zone uses an irregular polygon (not a rectangle) to exclude
a trapezoidal dead zone at the bottom-centre of the frame -- this prevents
false positives from close-up floor content directly ahead of the robot.

    x=0          x=250  x=390       x=640
     |              |      |             |
y=100+--------------------------------------------+  <- detection starts
     |                                             |
     |           MAIN BLOCKS ROI                  |  (red / green / magenta)
     |                                             |
y=295|              +------+                       |  <- notch top (platform)
     |             /        \\                      |
y=360+------------/          \\---------------------+  <- frame bottom
     x=180                   x=460

     +--------- dead zone (notch) ----------------+
       blocks here are too close / on
       the floor and should be ignored
"""

from __future__ import annotations

import os
import time
from collections import deque
from typing import Dict, List, Optional, Tuple

import cv2
import numpy as np

# ─────────────────────────────────────────────────────────────────────────────
# TUNABLE CONSTANTS
# Edit values here only — never scatter magic numbers through the rest of the
# code.  All coordinates are in full-frame pixels (origin = top-left of the
# 640×360 image).
# ─────────────────────────────────────────────────────────────────────────────

USE_LAB = False  # False → HSV detection (faster, good indoors)
# True  → LAB detection (more lighting-robust)

FRAME_WIDTH = 640
FRAME_HEIGHT = 360
FRAME_MIDPOINT_X = FRAME_WIDTH // 2
SMOOTH_N = 0  # majority-vote window for FrameSmoother

# ── HSV colour ranges ─────────────────────────────────────────────────────────
# Format: np.array([H, S, V]).  H ∈ [0,180], S/V ∈ [0,255] in OpenCV HSV.
# Red wraps around H=0/180, so two ranges are ORed together.
HSV_RANGES = {
    'LOWER_RED_1':   np.array([ 11,  43,  55]),  'UPPER_RED_1':   np.array([  8, 218, 224]),
    'LOWER_RED_2':   np.array([170,  43,  55]),  'UPPER_RED_2':   np.array([180, 218, 224]),
    'LOWER_GREEN':   np.array([ 29,  65,  15]),  'UPPER_GREEN':   np.array([ 98, 252, 197]),
    'LOWER_BLACK':   np.array([  0,   0,  15]),  'UPPER_BLACK':   np.array([134,  79, 116]),
    'LOWER_ORANGE':  np.array([  8,  41, 174]),  'UPPER_ORANGE':  np.array([ 17, 170, 255]),
    'LOWER_MAGENTA': np.array([157, 138,  62]),  'UPPER_MAGENTA': np.array([169, 210, 255]),
    'LOWER_BLUE':    np.array([ 89,  28,  45]),  'UPPER_BLUE':    np.array([134, 194, 220]),
}

LAB_RANGES = {
    'LOWER_RED_1':   np.array([ 11,  43,  55]),  'UPPER_RED_1':   np.array([  8, 218, 224]),
    'LOWER_RED_2':   np.array([170,  43,  55]),  'UPPER_RED_2':   np.array([180, 218, 224]),
    'LOWER_GREEN':   np.array([ 29,  65,  15]),  'UPPER_GREEN':   np.array([ 98, 252, 197]),
    'LOWER_BLACK':   np.array([  0,   0,  15]),  'UPPER_BLACK':   np.array([134,  79, 116]),
    'LOWER_ORANGE':  np.array([  8,  41, 174]),  'UPPER_ORANGE':  np.array([ 17, 170, 255]),
    'LOWER_MAGENTA': np.array([157, 138,  62]),  'UPPER_MAGENTA': np.array([169, 210, 255]),
    'LOWER_BLUE':    np.array([ 89,  28,  45]),  'UPPER_BLUE':    np.array([134, 194, 220]),
}

# ── Rectangular ROI zones ─────────────────────────────────────────────────────
# Format: (x, y, width, height) in full-frame pixels.
# These are used for walls, the floor line strip, and close-range blocks.
# The main_blocks zone is a POLYGON — see MAIN_BLOCKS_POLY below.
ROI = {
    "wall_left": (0, 160, 135, 150),
    "wall_right": (505, 160, 135, 150),
    "wall_inner_left": (0, 285, 100, 100),
    "wall_inner_right": (505, 285, 135, 100),
    "line": (150, 280, 60, 20),#(250, 220, 155, 20),
    "line_2": (430, 280, 60, 20),
    "close_block": (250, 100, 140, 40),
    "close_black": (250, 100, 140, 40),
    "parking_wall": (250, 100, 140, 40),
    "last_wall": (280, 20, 80, 20),
    "last_wall_2": (260, 90, 80, 20),

}

# ── Polygonal ROI for main block detection ────────────────────────────────────
# All coordinates are in FRAME-SLICE space (y values have _GLOBAL_Y_OFFSET
# already subtracted, because the polygon mask is applied to frame_slice).
#
# Shape: full-width rectangle with a trapezoidal notch cut from the bottom
# centre.  The notch excludes the area directly in front of the robot where
# floor content / very-close blocks cause false detections.
#
#   Slice coords (y = frame_y − 100):
#
#   (0,0) ──────────────────────────────── (640,0)
#     │                                        │
#     │           detection zone               │
#     │                                        │
#   (0,260) ─── (180,260)          (460,260) ── (640,260)
#                        \        /
#                    (250,195)──(390,195)
#                         notch top
#
# To adjust the notch:
#   • x=180 / x=460  →  width of notch at the bottom (wider = more excluded)
#   • x=250 / x=390  →  width of the raised platform (narrower = steeper walls)
#   • y=195           →  height of the notch (lower value = taller notch)
MAIN_BLOCKS_POLY = np.array(
    [
        [  0,   0],   # ① top-left
        [640,   0],   # ② top-right
        [640, 360],   # ③ bottom-right
        [425, 360],   # ④ notch: bottom-right corner
        [425, 250],   # ⑤ notch: top-right corner
        [215, 250],   # ⑥ notch: top-left corner
        [215, 360],   # ⑦ notch: bottom-left corner
        [  0, 360],   # ⑧ bottom-left
    ],
    dtype=np.int32,
)

# ── Minimum contour areas ─────────────────────────────────────────────────────
# Contours smaller than these thresholds are discarded as noise.
MIN_AREA = {
    "wall": 800 ,  # black wall segments
    "block": 800,  # red / green blocks in main zone
    "close_block": 100,  # blocks in close_block zone (larger apparent size)
    "magenta": 500,  # magenta parking marker
    "line": 100,  # floor line strip (very thin ROI → small area)
    "LastWall": 100,
    "LastWall2": 200,
    
}

# ── Draw colours (BGR) ───────────────────────────────────────────────────────
COLORS = {
    "red": (0, 0, 255),
    "green": (0, 255, 0),
    "orange": (0, 165, 255),
    "blue": (255, 0, 0),
    "black": (255, 255, 255),
    "magenta": (255, 0, 255),
    "roi": (255, 255, 0),
    "text": (255, 255, 255),
}

# ── Global detection Y bounds ─────────────────────────────────────────────────
# Detection only runs on frame[_GLOBAL_Y_OFFSET : _GLOBAL_Y_END, :].
# Anything above y=100 is ignored (sky / top of arena wall with no useful info).
_GLOBAL_Y_OFFSET = 10
_GLOBAL_Y_END = FRAME_HEIGHT  # 360 for 640×360
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

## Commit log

2026-07-20 second commit
    [all part 3d print file.3mf, an waveshare 5 inch dsi lcd.STL, an_6_12_holder.STL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]
2026-08-10 few placeholders remaining
    [Front wheel.STL, back Gear Mount.STL, back rpi mount.STL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]
2026-08-10 Update README.md
    Ackerman Geometry paragraph → Parallel linkage paragraph
    + Added trade-offs of using parallel linkage v/s ackerman
    + Added Differential gearbox small paragraph
2026-08-10 team photo added
    [all part 3d print file.3mf]
2026-08-12 added logs and clean extra data
    [all part 3d print file.3mf]
2026-08-12 document added
    [all part 3d print file.3mf, an waveshare 5 inch dsi lcd.STL, an_6_12_holder.STL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]
2026-10-07 v1.1 Commit - Post-Nationals. Details in extended body (click on this commit)
    This is our code and documentation after the National Competition, which adds all changes since Aug 12. We have updated the code with refining and error-proofing the camera pipeline and obstacle/open scripts, and made fallback cases for all based on problems we encountered. We have also attached more multimedia and documentation, including information and videos about our performance at Nationals, and more diagrams and setup files
